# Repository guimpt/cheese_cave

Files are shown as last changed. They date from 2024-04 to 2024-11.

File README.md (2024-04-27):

# Cheese cave
## The project
Are you ready to embark on your cheese-making journey? Picture this: crafting your own artisanal cheeses in the comfort of your own home. But wait, before you dive into the world of curds and whey, let's talk about the indispensable tool you'll need – the cheese cave.

Cheese caves provide the optimal environment for cheese aging, ensuring that your creations develop the perfect flavor and texture. While many suggest repurposing a wine fridge for this purpose, I've found that their temperature control leaves much to be desired.

Introducing this project: a complete overhaul of the control electronics in your standard wine fridge, transforming it into a precise cheese cave with an astonishing accuracy of ±0.1ºC.

Here's what the project entails:
 - Electronics Design and Firmware: all the necessary files for replicating the project, from the circuit schematics to the firmware code, are provided.
 - Fabrication Files: easily order the semi-assembled PCB from JLCPCB and gather the remaining components from LCSC.

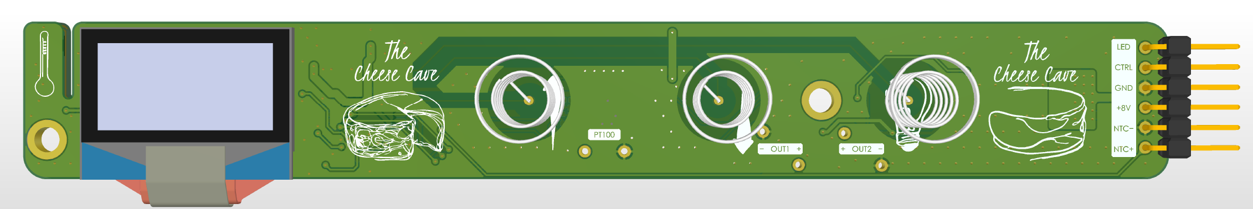
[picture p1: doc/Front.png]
Front Electronics

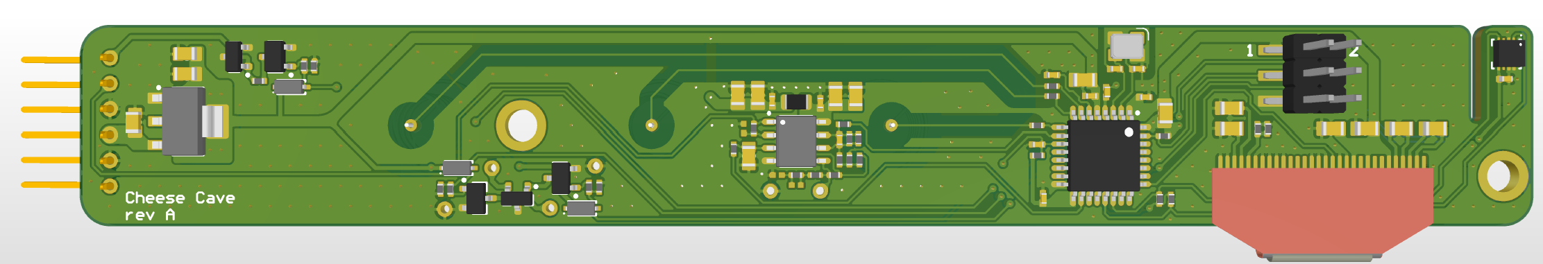
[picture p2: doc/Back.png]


## Specifications:
 - Utilizes STM32F042 for reliable and cheap performance.
 - Implements precise circuitry to maintain temperature control with PT100, NTC, or SHT30 sensors.
 - Features two MOSFET outputs for controlling mist makers, in order to implement humidity regulation (currently not implemented in the provided firmware).
 - Boasts a user-friendly OLED display with large numerical readouts and a control bar indicating the control action.
 - Equipped with touch sensors for convenient adjustment of fridge temperature and lighting.

## Compatible Fridges:
 - The controller is compatible with numerous wine fridges on the market.
 - Specifically designed as a replacement for the 3FX-136 / QC1218B wine fridge digital controllers.
 - If your fridge sports two seven-segment displays and three touch buttons, chances are it's equipped with the same controller, making it a seamless upgrade.

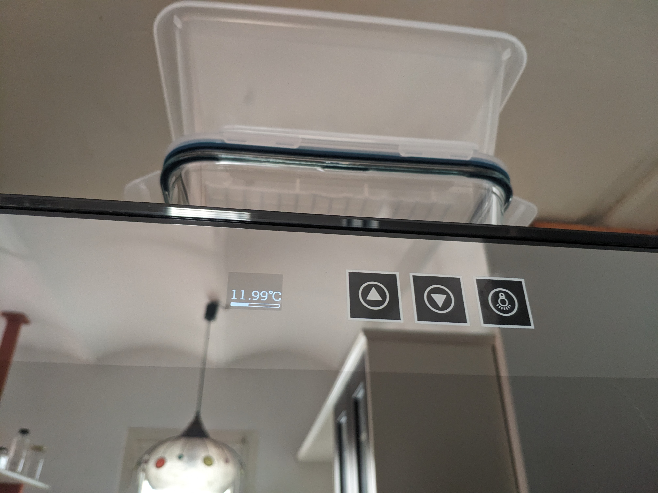
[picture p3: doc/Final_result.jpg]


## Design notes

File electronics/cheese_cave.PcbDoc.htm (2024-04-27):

Reporting Options

# File in Previous Format

Date | : | 12/26/2023
Time | : | 11:23:59 AM
Filename | : | C:\Users\Public\Documents\Altium\cheese_cave\cheese_cave.PcbDoc

Version | Warning

This file was generated by an earlier version of the software

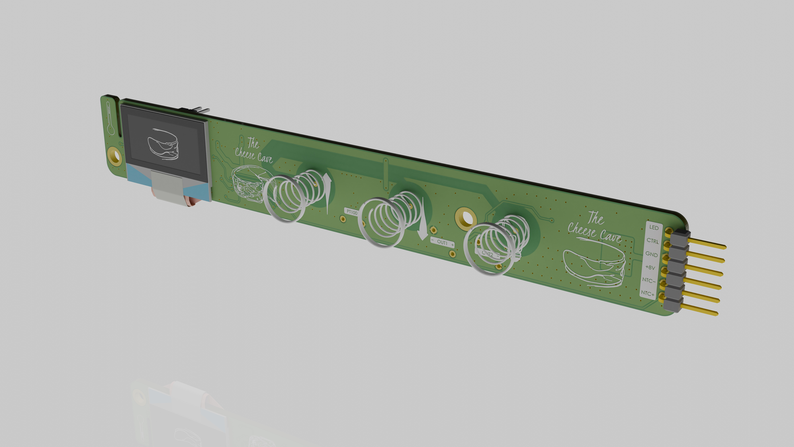
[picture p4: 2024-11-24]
doc/render1.jpg

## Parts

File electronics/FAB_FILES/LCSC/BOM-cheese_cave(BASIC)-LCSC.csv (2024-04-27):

Name | Designator | Footprint | LCSC
2x3p | J4 | 2x3p_conn | C124390
1x6p | J5 | 1X6P_CONN | C7501293
STM32F042K6T6 | U1 | LQFP32-ST | C69216
oled | U2 | OLED_096_SSD1306 | C2890596
SHT30 | U3 | SHT30-DIS-B2.5KS | C77361
OPA2330AIDR | U4 | SOIC8 | C128746

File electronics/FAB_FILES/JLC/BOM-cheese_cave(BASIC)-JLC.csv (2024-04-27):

Name | Designator | Footprint | LCSC
100n | C1, C2, C3, C12, C16, C19, C20, C23 | C0402 | C1525
10n | C4 | C0402 | C15195
1u | C5, C10, C11, C15, C18, C21, C24, C27, C28 | C0805 | C28323
4u7 | C6, C25 | C0805 | C1779
10p | C7, C8 | C0402 | C32949
22n | C9 | C0402 | C1532
10u | C13, C14, C17, C22 | C0805 | C15850
2u2 | C26 | C0805 | C377773
1N5819WS | D1, D2, D6 | SOD323 | C191023
12V | D4, D5 | SOT23_protek | C32677
100R | L1 | L0805 | C1015
AO3400A | Q1, Q2, Q3 | SOT23_alphaomega | C20917
5k1 | R1, R2, R18, R19 | R0402 | C25905
1k | R3, R4, R5, R6, R7, R14, R15, R16, R17, R23, R24 | R0402 | C11702
1M | R8, R21, R28, R29, R30 | R0402 | C26083
10k | R9, R11 | R0402 | C25744
0R | R10 | R0402 | C17168
100R | R12, R20 | R0402 | C25076
33R | R22 | R0402 | C25105
10R | R25 | R0402 | C25077
AMS1117-3.3 | U5 | SOT223 | C6186
16MHz | Y1 | SMD3225-4P | C13738

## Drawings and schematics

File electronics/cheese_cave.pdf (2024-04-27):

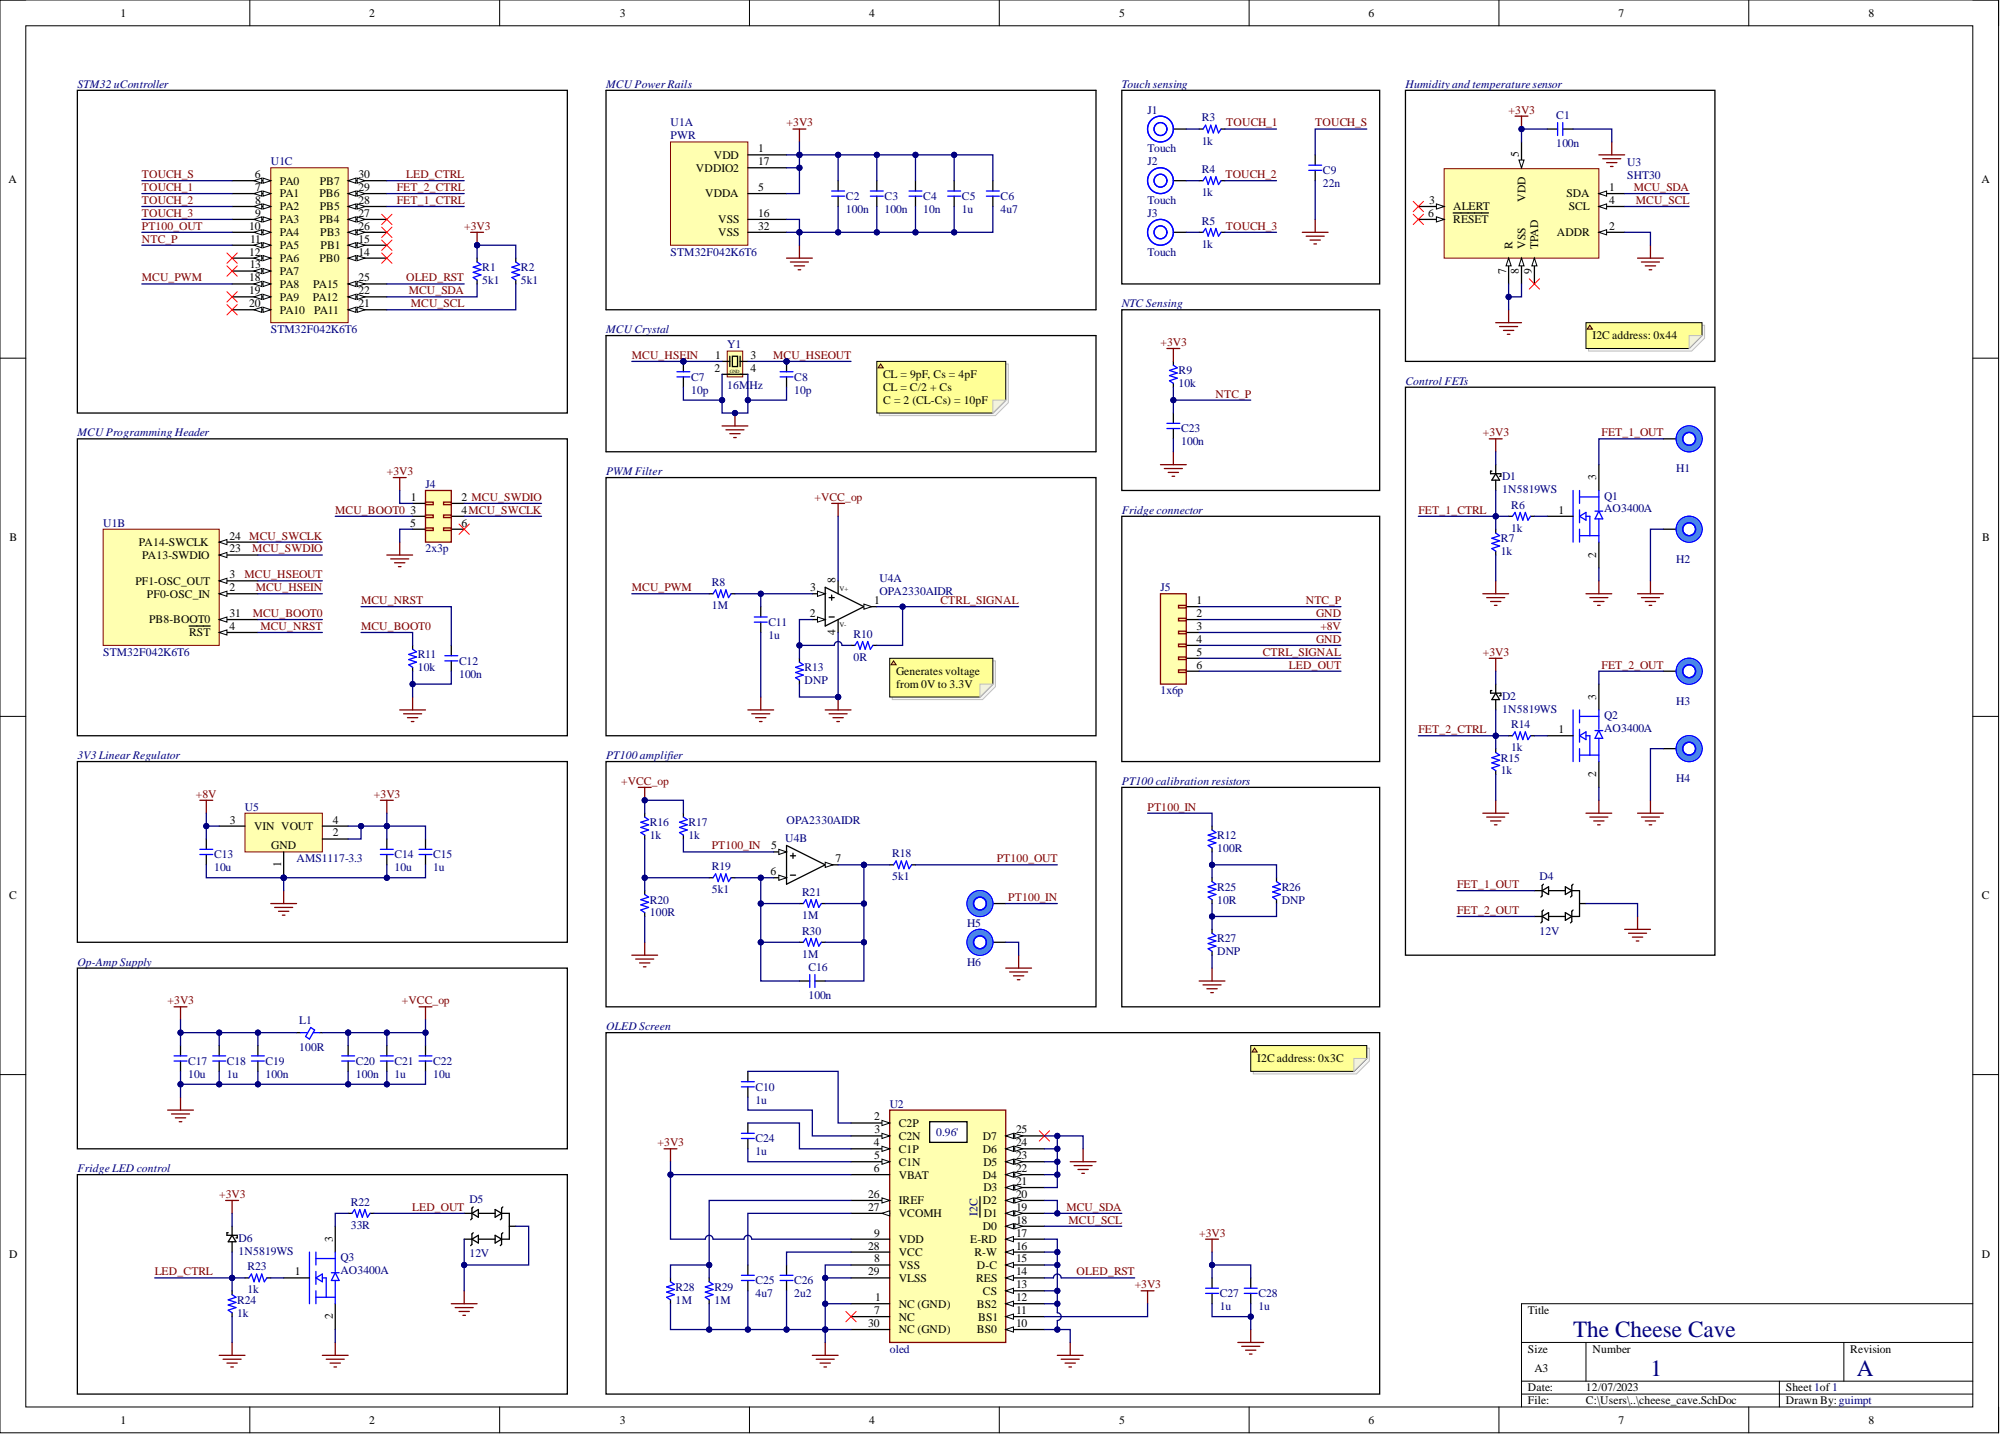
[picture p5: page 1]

C2 4 | 4
1 u | 5

2 7
9 | MCU _SCL

2 9

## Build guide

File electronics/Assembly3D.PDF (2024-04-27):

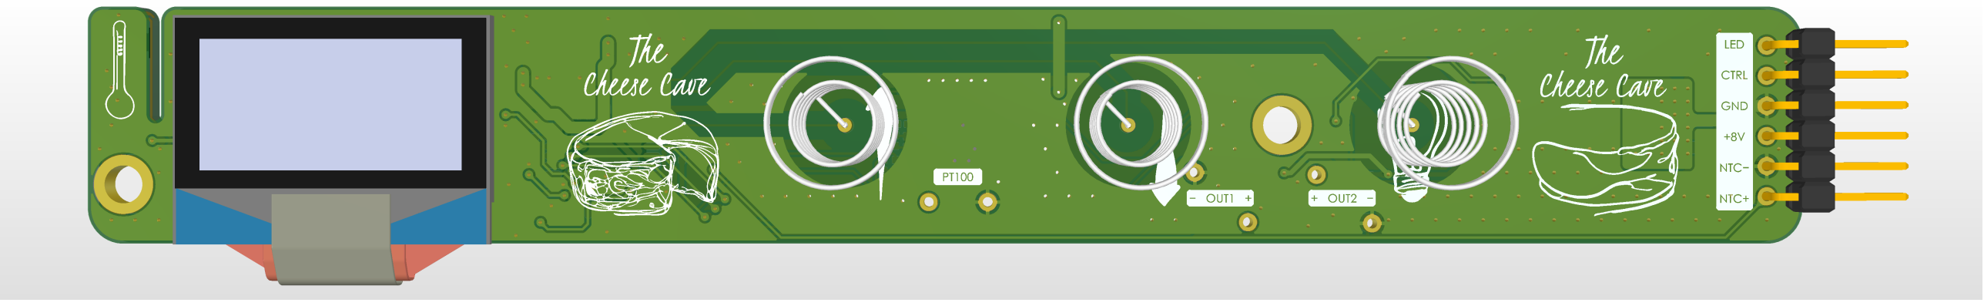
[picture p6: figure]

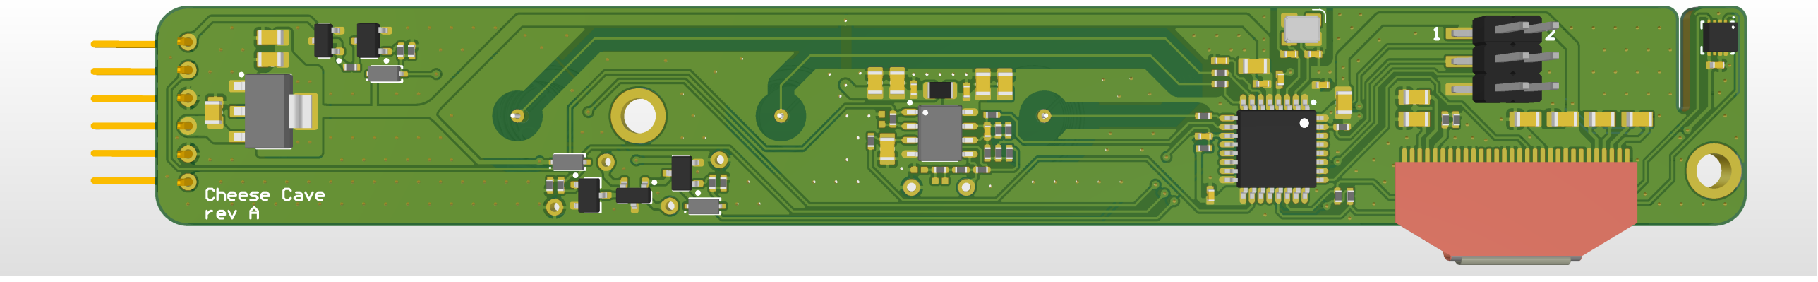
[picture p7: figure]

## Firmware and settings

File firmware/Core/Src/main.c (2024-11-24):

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
/* Includes ------------------------------------------------------------------*/
#include "main.h"
#include "touchsensing.h"

/* USER CODE BEGIN Includes */

#include "ssd1306.h"
#include "display.h"
#include "sh30.h"
#include "pt100.h"
#include "ntc.h"
#include "pidLoop.h"
/* USER CODE END Includes */

ADC_HandleTypeDef hadc;
DMA_HandleTypeDef hdma_adc;

I2C_HandleTypeDef hi2c1;

TIM_HandleTypeDef htim1;

TSC_HandleTypeDef htsc;

void SystemClock_Config(void);
static void MX_GPIO_Init(void);
static void MX_DMA_Init(void);
static void MX_TSC_Init(void);
static void MX_ADC_Init(void);
static void MX_I2C1_Init(void);
static void MX_TIM1_Init(void);
/* USER CODE BEGIN PFP */
void user_interface(void);

SSD1306Display ssd1306;
SH30 sh30;
ANALOG analog;
PT100 pt100;
NTC ntc;
PID pid;

float target_temp;
uint8_t int_target;
float filt_temp;
uint32_t last_target_change = 0;
uint32_t light_press_start = 0;
uint8_t update_display;
uint8_t show_sh30 = 0;

TSL_StateId_enum_T last_states[3];
TSL_StateId_enum_T new_states[3];

/* USER CODE END PFP */

/**
  * @brief  The application entry point.
  * @retval int
  */
int main(void)
{
  /* MCU Configuration--------------------------------------------------------*/

  /* Reset of all peripherals, Initializes the Flash interface and the Systick. */
  HAL_Init();

  /* Configure the system clock */
  SystemClock_Config();

  /* Initialize all configured peripherals */
  MX_GPIO_Init();
  MX_DMA_Init();
  MX_TSC_Init();
  MX_ADC_Init();
  MX_I2C1_Init();
  MX_TIM1_Init();
  MX_TOUCHSENSING_Init();
  /* USER CODE BEGIN 2 */

  // Screen
  ssd1306.i2c_handle = &hi2c1;
  ssd1306.reset_pin = OLED_RST_Pin;
  ssd1306.reset_port = OLED_RST_GPIO_Port;

  if (ssd1306Init(&ssd1306) != HAL_OK){
	  while(1);
  }

  sh30.i2c_handle = &hi2c1;

  bootLogo(&ssd1306);

  // Humidity sensor
  sh30Init(&sh30);

  // Analog inputs
  analog.adc_handle = &hadc;
  analog.raw_pt100 = &analog.dma_buffer[0];
  analog.raw_ntc = &analog.dma_buffer[1];
  analog.raw_int_temp = &analog.dma_buffer[2];
  analog.raw_int_ref = &analog.dma_buffer[3];

  pt100.analog = &analog;
  ntc.analog = &analog;

  HAL_ADCEx_Calibration_Start(analog.adc_handle);

  // Get temperature from NVM
  int_target = (uint8_t)*((uint16_t*)NVM_BASE_ADDRESS);
  if (*((uint16_t*)NVM_BASE_ADDRESS) == 0xFFFF){
	  int_target = 100;
  }
  target_temp = (float)int_target / 10.0 + 0.005;


  // PWM
  htim1.Instance->CCR1 = 1023;
  HAL_TIM_PWM_Start(&htim1, PWM_CTRL_CHANNEL);


  // Clear display
  HAL_Delay(1000);
  displayInit(&ssd1306);


  // Touch sensor initialization
  tsl_user_Init();

  // PID initialization
  pid.kp_int = -104858;
  pid.ki_int = 1;
  pid.Umin_int = 0;
  pid.Umax_int = 1023 * MULTIPLIER;

  pidLoop_Initialize(&pid);

  uint8_t first_loop = 1;

  ssd1306SetContrast(&ssd1306, 10);

  /* USER CODE END 2 */

  /* Infinite loop */
  /* USER CODE BEGIN WHILE */
  while (1)
  {
	  // Read temperatures
	  HAL_ADC_Start_DMA(analog.adc_handle, (uint32_t*)analog.dma_buffer, 4);
	  analog.dma_flag = 0;
	  while(!analog.dma_flag);
	  pt100UpdateTemperature(&pt100);
	  NTCUpdateTemperature(&ntc);
	  sh30ReadData(&sh30);

	  if (first_loop) filt_temp = pt100.temperature;
	  else  filt_temp = filt_temp * (1.0 - FILT) + pt100.temperature * FILT;
	  first_loop = 0;

	  // Loop update
	  pid.xp_k = (int32_t)((target_temp - filt_temp) * (float)MULTIPLIER);
	  pidLoop_Update(&pid);
	  htim1.Instance->CCR1 = 1023 - pid.y_k / MULTIPLIER;

	  uint32_t tickstart = HAL_GetTick();

	  update_display = 1;
	  while((HAL_GetTick() - tickstart) < 1000)
	  {
		  user_interface();
		  HAL_Delay(1);
	  }
    /* USER CODE END WHILE */

    /* USER CODE BEGIN 3 */
  }
  /* USER CODE END 3 */
}

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
/* USER CODE BEGIN 4 */
// Called when buffer is completely filled
void HAL_ADC_ConvCpltCallback(ADC_HandleTypeDef* hadc) {
	analog.dma_flag = 1;
}

void user_interface(void){
	tsl_user_Exec();

	new_states[0] = MyTKeys[0].p_Data->StateId;
	new_states[1] = MyTKeys[1].p_Data->StateId;
	new_states[2] = MyTKeys[2].p_Data->StateId;

	// Check buttons
	if((new_states[0] == TSL_STATEID_DETECT) && (new_states[0] != last_states[0])){
		// LED key
		HAL_GPIO_TogglePin(LED_GPIO_Port, LED_Pin);
		light_press_start = HAL_GetTick();
	}
	else if ((new_states[0] != TSL_STATEID_DETECT) && (last_states[0] == TSL_STATEID_DETECT)){
		if ((HAL_GetTick() - light_press_start) > 5000){
			show_sh30 = 1;
			last_target_change = HAL_GetTick();
			update_display = 1;
		}
	}
	else if((new_states[1] == TSL_STATEID_DETECT) && (new_states[1] != last_states[1])){
		// DOWN key
		int_target -= 1;
		target_temp = (float)int_target / 10.0 + 0.005;
		last_target_change = HAL_GetTick();
		update_display = 1;
	}
	else if((new_states[2] == TSL_STATEID_DETECT) && (new_states[2] != last_states[2])){
		// UP key
		int_target += 1;
		target_temp = (float)int_target / 10.0 + 0.005;
		last_target_change = HAL_GetTick();
		update_display = 1;
	}

	last_states[0] = new_states[0];
	last_states[1] = new_states[1];
	last_states[2] = new_states[2];

	// Update display
	if (update_display){
		update_display = 0;
		// Save to NVM
	    FLASH_EraseInitTypeDef flash_erase_struct;
	    uint32_t error_status;
	    HAL_FLASH_Unlock();

	    flash_erase_struct.TypeErase = FLASH_TYPEERASE_PAGES;
	    flash_erase_struct.PageAddress = NVM_BASE_ADDRESS;
	    flash_erase_struct.NbPages = 1;

	    HAL_FLASHEx_Erase(&flash_erase_struct, &error_status);

	    HAL_FLASH_Program(FLASH_TYPEPROGRAM_HALFWORD, NVM_BASE_ADDRESS, (uint16_t)int_target);

	    HAL_FLASH_Lock();

		if ((HAL_GetTick() - last_target_change) < 2000){
			if (show_sh30){
				if ((HAL_GetTick() - last_target_change) < 1000) {
					writeTemp(&ssd1306, sh30.humidity, 1);
					ssd1306UpdateDisplay(&ssd1306);
					ssd1306SetContrast(&ssd1306, 100);
				}
				else {
					writeTemp(&ssd1306, sh30.temperature, 0);
					ssd1306UpdateDisplay(&ssd1306);
					ssd1306SetContrast(&ssd1306, 100);
				}
			}
			else{
				writeTemp(&ssd1306, target_temp, 0);
				ssd1306UpdateDisplay(&ssd1306);
				ssd1306SetContrast(&ssd1306, 100);
			}
		}
		else {
			show_sh30 = 0;
			writeTemp(&ssd1306, filt_temp, 0);
			drawBar(&ssd1306, (pid.y_k / MULTIPLIER)/10);
			ssd1306UpdateDisplay(&ssd1306);
			ssd1306SetContrast(&ssd1306, 10);
		}
	}

}

/* USER CODE END 4 */
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


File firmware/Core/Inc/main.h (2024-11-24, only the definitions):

#define TOUCH_S_Pin GPIO_PIN_0
#define TOUCH_S_GPIO_Port GPIOA
#define TOUCH_LED_Pin GPIO_PIN_1
#define TOUCH_LED_GPIO_Port GPIOA
#define TOUCH_D_Pin GPIO_PIN_2
#define TOUCH_D_GPIO_Port GPIOA
#define TOUCH_U_Pin GPIO_PIN_3
#define TOUCH_U_GPIO_Port GPIOA
#define PT100_Pin GPIO_PIN_4
#define PT100_GPIO_Port GPIOA
#define NTC_Pin GPIO_PIN_5
#define NTC_GPIO_Port GPIOA
#define PWM_CTRL_Pin GPIO_PIN_8
#define PWM_CTRL_GPIO_Port GPIOA
#define OLED_RST_Pin GPIO_PIN_15
#define OLED_RST_GPIO_Port GPIOA
#define FET1_Pin GPIO_PIN_5
#define FET1_GPIO_Port GPIOB
#define FET2_Pin GPIO_PIN_6
#define FET2_GPIO_Port GPIOB
#define LED_Pin GPIO_PIN_7
#define LED_GPIO_Port GPIOB
#define VREFINT_CAL_ADDRESS 0x1FFFF7BA
#define PWM_CTRL_CHANNEL	TIM_CHANNEL_1
#define NVM_BASE_ADDRESS	0x08007C00UL

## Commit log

2024-04-27 First commit that includes all files.
    [cheese_cave.PcbLib, cheese_cave.PrjPcb, cheese_cave.SchDoc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]
2024-04-27 Addition of fabrications files.
    [BOM-cheese_cave(BASIC)-JLC.csv, BOM-cheese_cave(BASIC)-LCSC.csv, Pick Place for cheese_cave(BASIC).csv]
2024-11-20 Changes (to be tested): - Target temperature is saved in NVM - Humidity is shown when light button is pressed for more than 5 seconds

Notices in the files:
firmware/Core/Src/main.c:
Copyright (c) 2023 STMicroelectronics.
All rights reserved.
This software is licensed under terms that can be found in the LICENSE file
